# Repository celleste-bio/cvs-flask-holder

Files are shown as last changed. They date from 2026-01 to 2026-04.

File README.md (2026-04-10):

# CVS (Cell Volume after Sedimentation) Apparatus

Parametric OpenSCAD implementations of the **CVS (Cell Volume after Sedimentation) Apparatus**.
 
This project provides a **parametric, 3D-printable model** of the CVS apparatus described by Mustafa et al. (2011). While the measurement method itself is established, this repository offers a flexible design that can be customized to fit any Erlenmeyer flask dimensions, optimizing it for 3D printing and laboratory use.

## Specification Tracking

Manufacturer-backed flask specification tracking lives in [specifications/erlenmeyer-specifications.csv](/root/cvs-flask-holder/specifications/erlenmeyer-specifications.csv) with supporting notes in [specifications/erlenmeyer-spec-sources.md](/root/cvs-flask-holder/specifications/erlenmeyer-spec-sources.md).

Project documentation lives in `documentation/`:

- [project-overview.md](/root/cvs-flask-holder/documentation/project-overview.md)
- [repo-map.md](/root/cvs-flask-holder/documentation/repo-map.md)
- [workflows.md](/root/cvs-flask-holder/documentation/workflows.md)
- [holder-traceability.md](/root/cvs-flask-holder/documentation/holder-traceability.md)
- [flask-id-index.md](/root/cvs-flask-holder/documentation/flask-id-index.md)

The current tracked manufacturer-specific plastic capped line is:

- Tarsons sterile flat-base polycarbonate Erlenmeyer cell culture flasks with vented HDPE closure
  - Source: https://www.tarsons.com/product/sterile-erlenmeyer-cell-culture-flask-flat-base-pc-with-vented-hdpe-closure/
  - Modeled sizes: `125`, `250`, `500`, `1000`, `2000` mL
  - Model folders: `models/tarsons_pc_vented_125ml` through `models/tarsons_pc_vented_2000ml`

The CSV also tracks additional manufacturer resources and metadata such as material family, capped vs. rimmed/open neck, base style, sterility, and closure style for future model work.

Smaller OpenSCAD comparison scenes are available in `scripts/`:

- `compare_classic_open.scad` for the original open-rim flask set
- `compare_tarsons_pc_vented.scad` for all Tarsons plastic capped vented flasks
- `compare_tarsons_pc_vented_small.scad` for Tarsons 125/250/500 mL
- `compare_tarsons_pc_vented_large.scad` for Tarsons 1000/2000 mL

## Scientific Context & Benefits

This apparatus holds Erlenmeyer flasks at a precise **60-degree angle**, transforming a standard flask into a precision measurement tool ("the poor man's real-time sensor").

### Why Use the 60° CVS Apparatus?
Standard flask markings are notoriously inaccurate (5-10% error margin) and designed for liquid volume, not biomass density. This apparatus offers three critical advantages:

#### 1. Amplified Resolution (The "Ruler" Effect)
**The Problem**: In a flat flask, sedimented cells spread in a thin, indistinguishable layer across the wide bottom.
**The 60° Solution**: By tilting the flask, cells are forced into the "corner" (junction of base and wall), concentrating the biomass into a tall column.
**Result**: A <1mm change in biomass (invisible on a flat bottom) becomes a **5–10mm change** along the angled wall, making it easily readable with a standard ruler.

#### 2. Consistency of "Packing"
**The Problem**: Cells (especially cocoa) form aggregates (clumps) that settle loosely and unevenly in vertical flasks due to friction.
**The 60° Solution**: This angle is the "goldilocks" tilt—steep enough for cells to slide to maximum packing density, but stable enough to prevent collapse.
**Result**: Ensures every measurement has uniform packing pressure, creating a **linear correlation to Fresh Weight (FW)**.

#### 3. Non-Destructive Monitoring
**The Problem**: Accurate biomass readings usually require transferring culture to a graduated cylinder or PCV tube, risking contamination and cell loss.
**The 60° Solution**: The apparatus measures the flask *as is*.
**Result**: **Zero contamination risk** and no lost cells. You can track the growth curve of the *exact same flask* throughout the entire cycle.

### Summary Comparison

| Feature | Erlenmeyer Markings | 60° CVS Apparatus |
| :--- | :--- | :--- |
| **Accuracy** | ± 10% (Approximate) | **High** (Correlates to Fresh Weight) |
| **Readability** | Very poor for thin layers | **High** (Vertical height is amplified) |
| **Contamination Risk** | Low | **Zero** (Flask remains sealed) |
| **Suitability for Cocoa** | Poor (Aggregates settle unevenly) | **Excellent** (Optimal packing) |

### Reference Material
> **Reference Paper:**
> Mustafa, N. R., de Winter, W., van Iren, F. & Verpoorte, R. (2011). **Initiation, growth and cryopreservation of plant cell suspension cultures**. *Nature Protocols*, 6(6), 715–742.

*Note: The apparatus provided here is a supplementary tool to facilitate the handling of flasks described in the protocol. It is not the invention claimed in the cited patent (US Patent 5,965,438), which relates to the cryopreservation method itself.*

## Prerequisites

To use and generate these models, you need:
1.  **Lua** (5.1 or later)
2.  **OpenSCAD** (for rendering)
3.  **Git** (to manage dependencies)

## Installation

Clone the repository and initialize the submodules:

```bash
git clone <repository-url>
cd erlenmeyer-holders
git submodule update --init --recursive
```

This will pull the necessary dependencies (`lua-utils` and `lua-openscad`) into the `dependencies/` directory.

## Deployment / Reproduction

To ensure a consistent environment for generating models and documentation, we provide a **Podman** container configuration.

### 1. Build and Run Container
Use the provided helper script to build the image and enter the container shell:

```bash
./deployment/build_and_run.sh
```

### 2. Run Tasks Inside Container
Once inside the container (which mounts the current directory to `/data`), you can run the standard workflows:

**Generate Models:**
```bash
./scripts/model_all.sh
```

**Generate Documentation (PDF):**
```bash
cd publications
make
```

**Slice Models (Generates G-code):**
```bash
./scripts/slice_all.sh
```
*(Note: The container includes a PrusaSlicer AppImage)*

**Package Tarsons Release Files:**
```bash
./scripts/package_tarsons_pc_vented.sh
```
This creates a `distribution/` directory and `.tar.gz` archive containing the final STL/BGCODE files plus a manifest that maps each file to manufacturer, catalog number, capacity, and source specifications.

## Repository Structure

- **`source/`**: Lua scripts replaced `parametric/` that define the parametric 3D geometry.
    - `flask.lua`: Generates the flask shape.
    - `holder.lua`: Generates the holder apparatus.
- **`scripts/`**: Helper shell scripts for batch processing.
- **`models/`**: Contains configuration and generated files for specific flask sizes.
    - **`[size]ml/`** (e.g., `100ml/`, `250ml/`):
        - `measurements.yaml`: Definition of flask dimensions.
        - `*.scad`: Generated OpenSCAD files.
- **`publications/`**: Files for generating the scientific paper documentation (PDF).

- **`dependencies/`**: Local dependencies (submodules).

## Publication

A scientific paper format of this documentation is available in the `publications/` directory. To generate the PDF:

```bash
cd publications
make
```

## Fabrication

We recommend the following equipment and software, which were used to validate the models:

*   **Printer**: [Original Prusa MK4S](https://www.prusa3d.com/product/original-prusa-mk4s-3d-printer/)
*   **Slicer**: [PrusaSlicer](https://www.prusa3d.com/page/prusaslicer_424/)

The provided `slice_all.sh` script is configured for PrusaSlicer CLI.

## Usage

### 1. Configure Dimensions
Edit the `measurements.yaml` file in the desired size folder (e.g., `100ml/measurements.yaml`) to match your specific flask dimensions.

For manufacturer-specific folders, keep two things separate:

- published dimensions copied directly from the source
- modeling assumptions needed by this geometry, such as outer neck diameter when a vendor only publishes inner neck diameter

For traceability, each `measurements.yaml` should also define:

- `flask_id`: full canonical ID for manifests and lookups
- `engraving_id`: short ID engraved on the printed holder
- `manufacturer`, `family_code`, `variant_code`, `capacity_ml`, `revision`: normalized metadata used to explain the ID

See [holder-traceability.md](/root/cvs-flask-holder/documentation/holder-traceability.md) for the full provenance and ID documentation.

The printed holder carries both provenance engravings on the two front base tabs: the Git commit hash on one tab and the short `engraving_id` on the other.

**Required Measurements:**

- **`total_height`**: Absolute height from base to top of rim.
- **`neck_height`**: Length of the neck (including the rim).
- **`base_diameter`**: Diameter of the base at its widest point.
- **`neck_diameter`**: Diameter of the neck (excluding the rim).

*(Note: `body_height` is automatically calculated as `total_height - neck_height`)*

**Example (250ml Flask):**

```yaml
total_height: 13.3  # cm
neck_height: 1.0    # cm (with rim)
base_diameter: 8.0  # cm
neck_diameter: 3.7  # cm (without rim)
```

### 2. Generate Models
Use Lua to run the parametric scripts.

**Generate a Flask Model:**
```bash
lua source/flask.lua models/100ml/measurements.yaml models/100ml/flask.scad
```

**Generate a Holder Model:**
```bash
lua source/holder.lua models/100ml/measurements.yaml models/100ml/holder.scad
```

**Generate a Holder with Flask Visualization:**
```bash
# The 'true' argument adds a visual ghost of the flask to check fit
lua source/holder.lua models/100ml/measurements.yaml models/100ml/holder_with_flask.scad true
```

### 3. Batch Processing
Use the provided shell scripts (ensure they are executable: `chmod +x *.sh`):

- **Generate All SCAD Files**:
  ```bash
  ./scripts/model_all.sh
  ```
- **Render All to STL**:
  ```bash
  ./scripts/render_all.sh
  ```
- **Slice All** (Requires PrusaSlicer CLI configuration):
  ```bash
  ./scripts/slice_all.sh
  ```
- **Run the Full Pipeline**:
  ```bash
  ./scripts/build_all.sh
  ```
  This generates SCAD files, renders STL files, slices BGCODE, and exports PNG previews for every `scripts/compare*.scad` scene into `artifacts/compare/`.
- **Package Manufacturer-Tracked Tarsons Outputs**:
  ```bash
  ./scripts/package_tarsons_pc_vented.sh
  ```

## License

**MIT License**

Copyright (c) 2026 Celleste Bio

Permission is hereby granted, free of charge, to any person obtaining a copy of this software and associated documentation files (the "Software"), to deal in the Software without restriction, including without limitation the rights to use, copy, modify, merge, publish, distribute, sublicense, and/or sell copies of the Software, and to permit persons to whom the Software is furnished to do so, subject to the following conditions:

The above copyright notice and this permission notice shall be included in all copies or substantial portions of the Software.

THE SOFTWARE IS PROVIDED "AS IS", WITHOUT WARRANTY OF ANY KIND, EXPRESS OR IMPLIED, INCLUDING BUT NOT LIMITED TO THE WARRANTIES OF MERCHANTABILITY, FITNESS FOR A PARTICULAR PURPOSE AND NONINFRINGEMENT. IN NO EVENT SHALL THE AUTHORS OR COPYRIGHT HOLDERS BE LIABLE FOR ANY CLAIM, DAMAGES OR OTHER LIABILITY, WHETHER IN AN ACTION OF CONTRACT, TORT OR OTHERWISE, ARISING FROM, OUT OF OR IN CONNECTION WITH THE SOFTWARE OR THE USE OR OTHER DEALINGS IN THE SOFTWARE.

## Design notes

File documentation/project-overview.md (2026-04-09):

# Project Overview

This repository contains a parametric CAD workflow for generating 3D-printable CVS (Cell Volume after Sedimentation) flask holders.

## Purpose

The holder fixes an Erlenmeyer flask at a repeatable tilt so sedimented biomass forms a readable column along the flask wall. The geometry is driven from flask dimensions stored in per-model YAML files.

## Core Design Idea

A flask model is defined by measurements in `models/<model>/measurements.yaml`.

From that YAML:

- `source/flask.lua` generates a flask visualization model
- `source/holder.lua` generates the printable holder geometry
- scripts in `scripts/` batch-generate SCAD, STL, BGCODE, and release packages

## Main Data Flow

1. Define or update a flask model in `models/.../measurements.yaml`.
2. Generate SCAD files from the Lua geometry sources.
3. Render STL files from SCAD.
4. Slice toolpaths for printing.
5. Package release artifacts when needed.

## Documentation Layout

Project-level documentation now lives in `documentation/`:

- `project-overview.md`: what the repo does and how it is organized
- `holder-traceability.md`: provenance and engraving model
- `flask-id-index.md`: registry of current short IDs and full IDs
- `repo-map.md`: structure guide for the repository
- `workflows.md`: practical generation and release workflow notes

## Specifications Layout

The `specifications/` directory is reserved for flask specification sources and source-backed records such as:

- manufacturer-backed specification tables
- source capture notes
- future source-specific supporting material

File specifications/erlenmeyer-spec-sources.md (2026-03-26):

# Erlenmeyer Specification Tracking

This repository now tracks manufacturer-backed Erlenmeyer flask specifications in [erlenmeyer-specifications.csv](/root/cvs-flask-holder/specifications/erlenmeyer-specifications.csv).

## Primary Modeling Source

- Tarsons: Sterile Erlenmeyer Cell Culture Flask, Flat base, PC with vented HDPE Closure
  - URL: https://www.tarsons.com/product/sterile-erlenmeyer-cell-culture-flask-flat-base-pc-with-vented-hdpe-closure/
  - Sizes published on the product page: 125, 250, 500, 1000, 2000 mL
  - Published dimensions captured in the dataset: bottom outer diameter, inner neck diameter, height without closure, height with closure, closure finish
  - Metadata captured: plastic, capped, vented, threaded, sterile, autoclavable, flat-base

## Additional Manufacturer Resources

- DWK Life Sciences, PYREX narrow-neck glass flasks
  - URL: https://www.dwk.com/pyrex-flasks-conical-narrow-neck-125-ml-113008d
  - Useful for glass, rimmed/open, narrow-neck reference dimensions
  - Product page exposes body OD, neck ID, and height

- DWK Life Sciences, DURAN narrow-neck glass flasks
  - URL: https://www.dwk.com/duran-erlenmeyer-flask-narrow-neck-1000-ml-212165409
  - Useful for ISO-style borosilicate glass reference families and larger capacities
  - Product page confirms glass material and narrow-neck family; dimensions should be pulled from the live spec table when modeling a specific size

- Thermo Fisher Scientific, Nalgene single-use PETG Erlenmeyer flasks
  - URL: https://www.thermofisher.com/order/catalog/product/ar/en/4115-0500
  - Useful for plastic, threaded, capped plain-bottom families
  - Family page covers vented and solid caps across 125, 250, 500, 1000, 2000, and 2800 mL

- Corning polycarbonate Erlenmeyer flasks
  - URL: https://ecatalog.corning.com/life-sciences/b2c/US/en/Bioprocess-and-Scale-up/Erlenmeyer-Flasks/Erlenmeyer-Flasks-Plastic/Corning%C2%AE-Polycarbonate-Erlenmeyer-Flask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
  - Useful for sterile disposable plastic flask families with vented and baffled variants
  - Family pages are good references for cap style, neck style, bottom style, sterility, and size availability

## Modeling Assumptions For Tarsons

Tarsons publishes `Inner Neck Diameter` and thread finish, but not the outer neck diameter required by this holder model. For the new Tarsons models:

- `total_height` uses the published `Height w/out closure`
- `base_diameter` uses the published `Bottom Outer Diameter`
- `neck_diameter` uses the published thread finish as the best available outer-neck proxy
- `neck_height` is an explicit modeling estimate and is marked as such in each `measurements.yaml`

If direct caliper measurements become available, update the Tarsons folders first and then regenerate the SCAD/STL outputs.

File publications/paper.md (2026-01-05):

---
title: "Parametric Design and Fabrication of CVS Apparatus: An Improved Method for Biomass Measurement"
author:
- Celleste Bio
date: 2026-01-05
abstract: |
  We present a parametric OpenSCAD implementation of the Cell Volume after Sedimentation (CVS) apparatus originally described by @mustafa2011initiation. By enabling the accessible fabrication of this tool via 3D printing, we provide an improved method for biomass measurement that is significantly faster, easier, and less traumatic to cell samples than traditional techniques. Our primary contribution is a fully customizable, parametric CAD design that allows researchers to adapt the apparatus to any Erlenmeyer flask dimension, facilitating widespread adoption of this non-destructive and sterile workflow.
bibliography: references.bib
csl: https://www.zotero.org/styles/nature
geometry:
  - margin=2cm
---

# Introduction

Accurate measurement of biomass in plant cell suspension cultures is frequently bottlenecked by methods that are either destructive, time-consuming, or prone to contamination. The CVS method offers a superior alternative—a "poor man's real-time sensor"—that transforms a standard flask into a precision measurement tool.

We provide a parametric model to democratize access to this method. Our goal is to replace ad-hoc laboratory setups with a robust, reproducible, and 3D-printable design. This approach minimizes the barrier to entry, allowing any laboratory to implement a rapid, non-destructive monitoring workflow tailored to their specific glassware inventory.

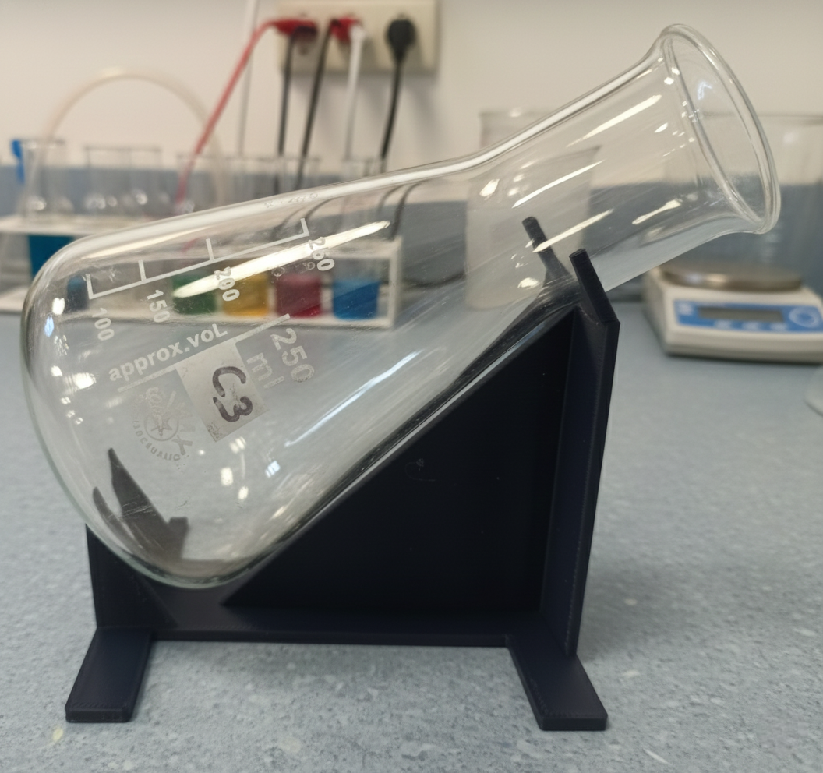
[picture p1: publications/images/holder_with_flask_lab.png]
CVS Apparatus in a laboratory setting.


# Parametric Model Configuration

To ensure the apparatus fits the flask securely and provides accurate sedimentation angles, the model requires specific dimensions of the user's flask. These are defined in a YAML configuration file.

The required measurements are:

*   **`total_height`**: The absolute vertical height of the flask from base to the top of the rim.
*   **`neck_height`**: The length of the neck, including the rim.
*   **`base_diameter`**: The diameter of the widest part of the base.
*   **`neck_diameter`**: The diameter of the neck (measured below the rim).

The **`body_height`** (the conical section) is automatically derived as `total_height - neck_height`.

## Example Configuration (250ml Flask)

For a standard 250ml Erlenmeyer flask, the configuration would be:

```yaml
# 250ml Flask Dimensions
total_height: 13.3   # cm
neck_height: 1.0     # cm (includes rim)
base_diameter: 8.0   # cm
neck_diameter: 3.7   # cm (excludes rim)
```

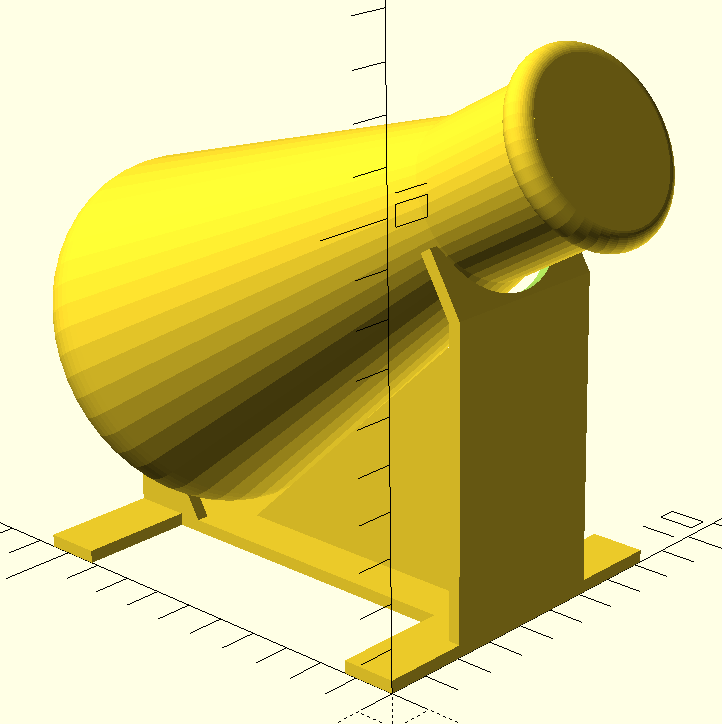
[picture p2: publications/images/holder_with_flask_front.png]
Front view: With Flask (Left) and Without Flask (Right).
 \ \ 
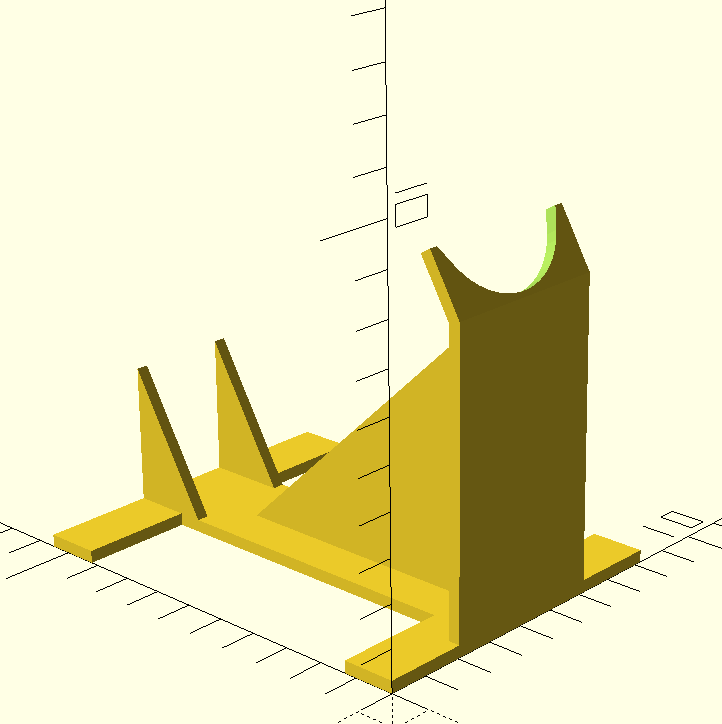
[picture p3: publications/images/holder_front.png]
Front view: Without Flask.


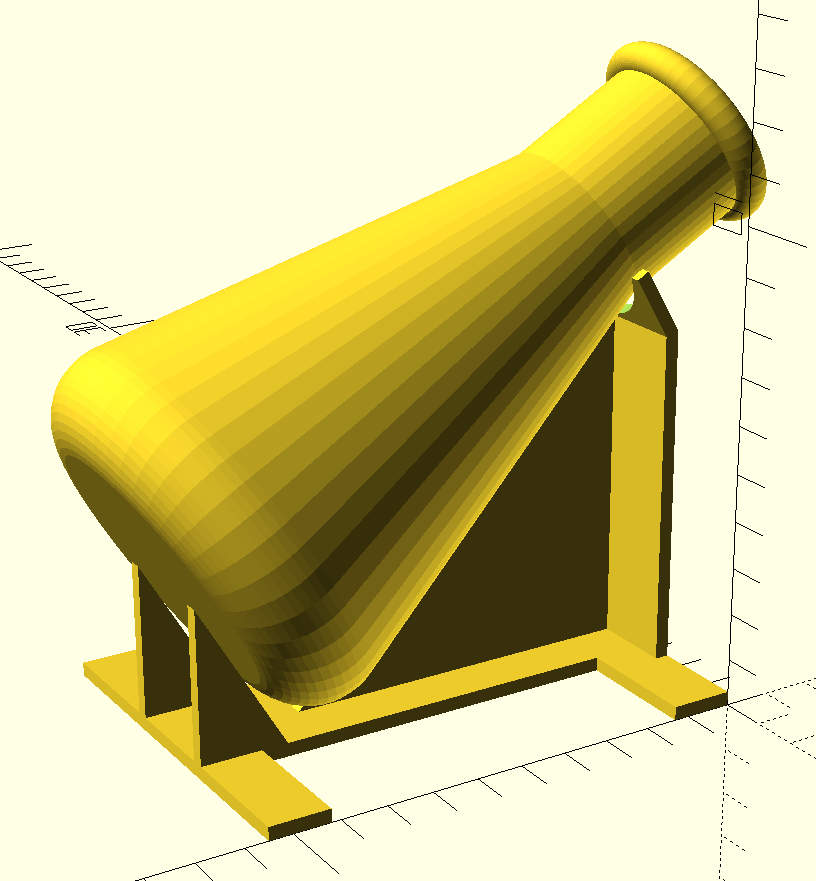
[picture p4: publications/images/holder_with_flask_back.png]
Back view: With Flask (Left) and Without Flask (Right).
 \ \ 
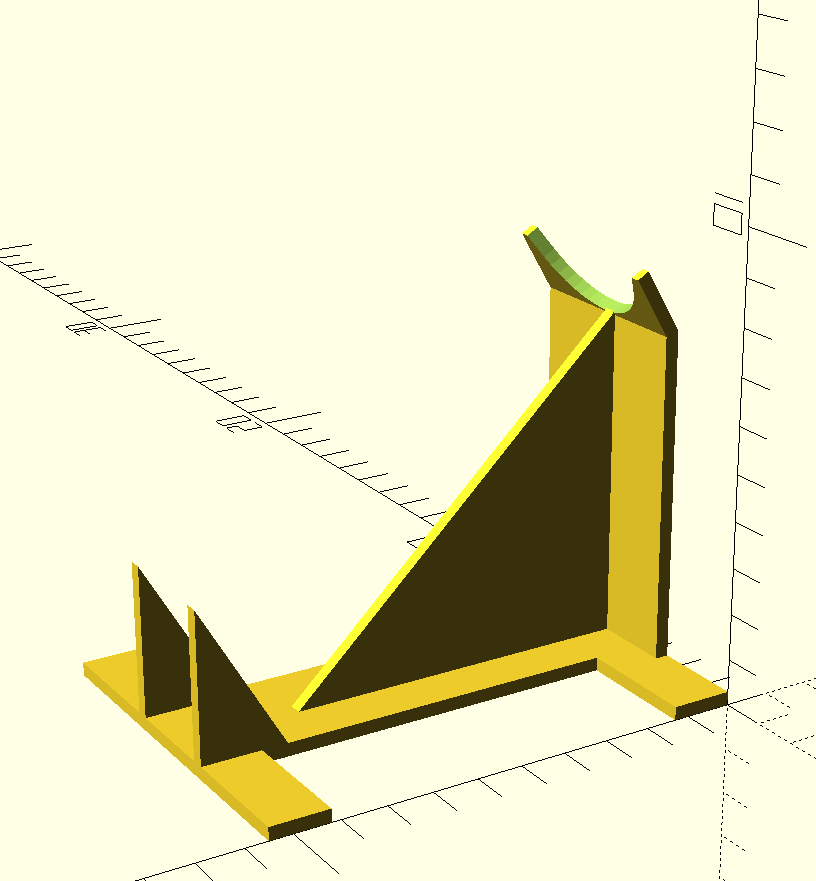
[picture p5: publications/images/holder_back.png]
Back view: Without Flask.


# Principles and Benefits

The CVS apparatus holds flasks at a fixed 60-degree angle, enabling a workflow that simplifies biomass monitoring while preserving sample integrity.

## Enhanced Readability
In a flat flask, sedimented cells spread in a thin, indistinguishable layer across the wide bottom. By tilting the flask, cells are forced into the junction of the base and the wall, concentrating the biomass into a tall column. This geometric amplification translates a negligible <1 mm height difference into a clear 5–10 mm change along the angled wall, making it faster and easier to read with a standard ruler.

## Standardized Measurement
Cells, particularly those of *Theobroma cacao* (cocoa), often form aggregates that settle unevenly in vertical flasks. The 60-degree angle provides an optimal tilt—steep enough for cells to slide to maximum packing density under gravity, yet stable enough to prevent collapse. This consistency eliminates the variability of manual handling and ensures distinct, reproducible measurements.

## Non-Traumatic and Sterile Workflow
Unlike traditional sampling which requires opening the flask and breaking the sterile barrier, this method measures the flask *as is*. This results in a completely **sterile workflow** with **zero contamination risk**. Furthermore, because the sample is not removed or mechanically disturbed, the process is non-traumatic for the cells, allowing for continuous monitoring of the exact same culture throughout its growth cycle.

# Method Comparison

We compare the CVS apparatus with the traditional **Packed Cell Volume (PCV)** method, which involves centrifuging a sub-sample of the culture (typically 10-15 mL) in a 50 mL Falcon tube. While PCV provides a direct volumetric measurement, it introduces significant drawbacks regarding sterility and sample integrity.

| Feature | Packed Cell Volume (PCV) | 60° CVS Apparatus |
| :--- | :--- | :--- |
| **Contamination Risk** | **High** (Breaks sterile barrier) | **Zero** (Flask remains sealed) |
| **Sample Representativeness** | **Variable** (Sub-sample dependent) | **Complete** (Measures whole culture) |
| **Material Loss** | **Yes** (Destructive sub-sampling) | **None** (Non-destructive) |
| **Time Cost** | **High** (Pipetting, Centrifugation) | **Low** (Instant visual read) |
| **Equipment** | **Significant** (Centrifuge, tubes, tips) | **Minimal** (3D Printed Holder, Ruler) |
| **Measurement Accuracy** | **High** (For the sub-sample) | **High** (Amplified height, correlates to fresh weight) |

# Fabrication

The models were optimized for fabrication using **Fused Deposition Modeling (FDM)** 3D printing. We utilized the **[Original Prusa MK4S](https://www.prusa3d.com/product/original-prusa-mk4s-3d-printer/)** 3D printer for its reliability and precision.

Preprocessing and slicing were performed using **[PrusaSlicer](https://www.prusa3d.com/page/prusaslicer_424/)**, which ensures optimal toolpath generation for structural integrity and print quality. The batch processing scripts provided in the repository utilize the PrusaSlicer CLI interface to automate the generation of G-code for multiple flask sizes.

# References
The apparatus described here serves as a supplementary tool to facilitate the handling of flasks described in the protocol by @mustafa2011initiation. Note that this tool is not the invention claimed in the cited patent (US Patent 5,965,438), which relates to the cryopreservation method itself.

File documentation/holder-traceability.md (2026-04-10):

# Holder Traceability

This document explains how holder provenance is encoded, how flask IDs are assigned, and how to trace a printed holder back to the exact modeled flask definition.

## Provenance Layers

Each holder is intended to carry two engraved identifiers:

- Git commit hash: identifies the code revision that generated the holder geometry
- `engraving_id`: identifies the intended flask model in a compact print-friendly format

Both markings are engraved into the two front base tabs so they remain visible from the same viewing side of the printed holder.

The engraved flask code is short on purpose. The full source-of-truth identity and supporting metadata live in the corresponding `measurements.yaml` file.

## Metadata Layers

Each flask model should define these metadata fields in `measurements.yaml`:

- `flask_id`: full canonical identifier used for indexing and documentation
- `engraving_id`: compact identifier engraved on the holder
- `manufacturer`: source manufacturer or `Generic`
- `family_code`: normalized family grouping such as `erlenmeyer` or `cellculture`
- `variant_code`: normalized variant such as `open` or `vented`
- `capacity_ml`: nominal flask capacity in mL
- `revision`: revision number for the modeled measurement definition

Manufacturer-specific models can also include:

- `catalog_no`
- `product_line`
- `source_url`
- published source dimensions
- notes about modeling assumptions

## Why Two IDs Exist

A single full identifier is useful for indexing but often too long for clean engraving. A single short identifier is easy to engrave but too compressed to serve as the only documentation key.

Using both solves that tradeoff:

- `engraving_id` keeps the physical holder readable
- `flask_id` keeps the repository searchable and explainable

## Engraving ID Format

```text
{maker}{capacity}{variant}{revision}
```

Examples:

- `G250O1` = Generic, 250 mL, open, revision 1
- `T250V1` = Tarsons, 250 mL, vented, revision 1
- `T1KV1` = Tarsons, 1000 mL, vented, revision 1

See [flask-id-index.md](/root/cvs-flask-holder/documentation/flask-id-index.md) for the code tables and current registry.

## Canonical Full ID Format

```text
{manufacturer}-{family_code}-{capacity_ml}-{variant_code}-v{revision}
```

Examples:

- `generic-erlenmeyer-0250-open-v1`
- `tarsons-cellculture-0250-vented-v1`

The full ID is the durable repository key and should be used in manifests, release notes, and any future packaging metadata.

## Example

```yaml
flask_id: tarsons-cellculture-0250-vented-v1
engraving_id: T250V1
manufacturer: Tarsons
family_code: cellculture
variant_code: vented
capacity_ml: 250
revision: 1
catalog_no: 444220
```

## How To Trace A Printed Holder

1. Read the Git commit engraving from the holder.
2. Read the short `engraving_id` from the adjacent front tab.
3. Look up the short ID in [flask-id-index.md](/root/cvs-flask-holder/documentation/flask-id-index.md).
4. Open the corresponding `models/.../measurements.yaml` file.
5. Use `flask_id`, source fields, and notes to recover the exact modeled flask definition.

## Authoring Rules

- Keep `engraving_id` short enough to print clearly.
- Keep `flask_id` descriptive and stable.
- Do not reuse an existing ID for different dimensions.
- Increment `revision` when modeled dimensions or dimensional interpretation change materially.
- Keep manufacturer source values and modeling assumptions separate when both are needed.

## Maintenance Workflow

When adding or revising a flask model:

1. Add or update the normalized metadata in `measurements.yaml`.
2. Assign a new `engraving_id` and `flask_id` if needed.
3. Update [flask-id-index.md](/root/cvs-flask-holder/documentation/flask-id-index.md).
4. Regenerate SCAD files so the physical engraving matches the metadata.
5. Regenerate downstream STL or toolpath artifacts as needed.

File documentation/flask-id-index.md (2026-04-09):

# Flask ID Index

This repository uses two ID layers for holder provenance:

- `engraving_id`: short code engraved on the holder
- `flask_id`: full canonical ID stored in `measurements.yaml`

The short code is optimized for readability and reliable printing. The full ID is optimized for indexing, search, and documentation.

## Engraving ID Format

```text
{maker}{capacity}{variant}{revision}
```

Examples:

- `G250O1` = Generic, 250 mL, open, revision 1
- `T250V1` = Tarsons, 250 mL, vented, revision 1
- `T1KV1` = Tarsons, 1000 mL, vented, revision 1

## Code Tables

### Maker Codes

- `G` = Generic or legacy reference flask
- `T` = Tarsons
- `D` = DWK
- `C` = Corning
- `H` = Thermo Fisher

### Capacity Codes

- `100`, `125`, `250`, `500` = capacity in mL
- `1K` = 1000 mL
- `2K` = 2000 mL
- `2P8K` = 2800 mL if needed in the future

### Variant Codes

- `O` = open rim
- `V` = vented cap
- `S` = solid or screw cap
- `B` = baffled

### Revision

The trailing number is the revision of the modeled measurement set.

- `1` = first tracked measurement definition
- `2` = updated measurement definition, same family and capacity

Increment the revision when the modeled dimensions or their interpretation change in a way that should remain traceable.

## Canonical Full ID Format

```text
{manufacturer}-{family_code}-{capacity_ml}-{variant_code}-v{revision}
```

Examples:

- `generic-erlenmeyer-0250-open-v1`
- `tarsons-cellculture-0250-vented-v1`

The full ID is the durable repo key. Use it in manifests, documentation, and any future packaging metadata.

## Current Registry

| Model Folder | Engraving ID | Full ID |
| :--- | :--- | :--- |
| `models/100ml` | `G100O1` | `generic-erlenmeyer-0100-open-v1` |
| `models/250ml` | `G250O1` | `generic-erlenmeyer-0250-open-v1` |
| `models/500ml` | `G500O1` | `generic-erlenmeyer-0500-open-v1` |
| `models/1000ml` | `G1KO1` | `generic-erlenmeyer-1000-open-v1` |
| `models/tarsons_pc_vented_125ml` | `T125V1` | `tarsons-cellculture-0125-vented-v1` |
| `models/tarsons_pc_vented_250ml` | `T250V1` | `tarsons-cellculture-0250-vented-v1` |
| `models/tarsons_pc_vented_500ml` | `T500V1` | `tarsons-cellculture-0500-vented-v1` |
| `models/tarsons_pc_vented_1000ml` | `T1KV1` | `tarsons-cellculture-1000-vented-v1` |
| `models/tarsons_pc_vented_2000ml` | `T2KV1` | `tarsons-cellculture-2000-vented-v1` |

## How To Trace A Printed Holder

1. Read the Git commit engraving and locate the code revision.
2. Read the short `engraving_id` and look it up in this index.
3. Open the matching `models/.../measurements.yaml` file.
4. Use `flask_id`, source fields, and notes to recover the exact modeled flask definition.

## Authoring Rules

- Keep `engraving_id` short enough to print clearly.
- Keep `flask_id` descriptive and stable.
- Do not recycle an existing ID for different dimensions.
- Bump the revision when measurements or modeling assumptions change materially.

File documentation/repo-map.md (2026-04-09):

# Repository Map

This document gives a practical map of the repository so it is easier to locate source code, generated artifacts, specifications, and publishing materials.

## Top-Level Layout

- `README.md`: short project entry point
- `documentation/`: project documentation and navigation aids
- `source/`: parametric geometry source code in Lua
- `models/`: per-flask model definitions and generated outputs
- `scripts/`: batch generation, rendering, slicing, comparison, and packaging helpers
- `specifications/`: source-backed flask specification records
- `distribution/`: packaged release outputs
- `artifacts/`: generated comparison images and similar derived outputs
- `deployment/`: containerized build environment helpers
- `publications/`: paper manuscript, references, and rendered publication assets
- `dimensions/`: exploratory dimensional analysis inputs and notes
- `dependencies/`: vendored or submodule dependencies used by the geometry code

## Source Code

### `source/`

- `flask.lua`: builds the flask reference geometry used for visualization and fit checks
- `holder.lua`: builds the printable holder geometry and engravings

## Model Definitions And Outputs

### `models/`

Each subdirectory represents one flask model.

Typical contents:

- `measurements.yaml`: source-of-truth dimensions and metadata
- `flask.scad`: generated flask geometry
- `holder.scad`: generated holder geometry
- `holder_with_flask.scad`: generated holder plus flask visualization
- `holder.stl`: rendered printable mesh
- `holder.bgcode`: sliced print output

Current families include:

- generic open Erlenmeyer reference sizes
- Tarsons vented cell culture flasks

## Scripts

### `scripts/`

Operational entry points:

- `model_all.sh`: generate SCAD for all models
- `render_all.sh`: render STL files
- `slice_all.sh`: slice print jobs
- `build_all.sh`: run the full main pipeline
- `package_tarsons_pc_vented.sh`: create Tarsons release packages

Comparison scenes:

- `compare_all.scad`
- `compare_classic_open.scad`
- `compare_tarsons_pc_vented.scad`
- `compare_tarsons_pc_vented_small.scad`
- `compare_tarsons_pc_vented_large.scad`

## Documentation

### `documentation/`

- `project-overview.md`: project-level orientation
- `workflows.md`: build and maintenance workflows
- `holder-traceability.md`: holder provenance model
- `flask-id-index.md`: short-ID registry and decoding table
- `repo-map.md`: this file

## Specifications

### `specifications/`

This directory is reserved for specification material and source-backed records:

- `erlenmeyer-specifications.csv`: tracked manufacturer or source rows
- `erlenmeyer-spec-sources.md`: notes about where each specification came from

## Publication Material

### `publications/`

- `paper.md`: manuscript source
- `references.bib`: bibliography
- `paper.pdf`: built paper output
- `images/`: paper figures

## Build Environment

### `deployment/`

- `Containerfile`: reproducible container definition
- `build_and_run.sh`: helper to enter the build environment

## Derived Output Areas

### `artifacts/`

Stores generated visual comparison outputs.

### `distribution/`

Stores packaged release bundles prepared for sharing or fabrication handoff.

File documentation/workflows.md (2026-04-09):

# Workflows

This document summarizes the main operational workflows for the repository.

## Model Authoring Workflow

1. Pick or create a model folder under `models/`.
2. Edit `measurements.yaml` with dimensions and metadata.
3. Assign `flask_id` and `engraving_id`.
4. Keep published source values and modeling assumptions separate when manufacturer data is incomplete.

## Geometry Generation Workflow

Use the batch generator:

```bash
./scripts/model_all.sh
```

This produces:

- `flask.scad`
- `holder.scad`
- `holder_with_flask.scad`

## Rendering Workflow

Render STL files from generated SCAD:

```bash
./scripts/render_all.sh
```

## Slicing Workflow

Generate printer toolpaths:

```bash
./scripts/slice_all.sh
```

## Full Build Workflow

Run the full generation pipeline:

```bash
./scripts/build_all.sh
```

This is the most convenient path when model definitions or generator logic changes.

## Packaging Workflow

For the tracked Tarsons vented family:

```bash
./scripts/package_tarsons_pc_vented.sh
```

This prepares a release bundle under `distribution/`.

## When To Regenerate Artifacts

Regenerate SCAD files when:

- `source/flask.lua` changes
- `source/holder.lua` changes
- any `measurements.yaml` changes
- engraving or provenance logic changes

Regenerate STL and slicing outputs when:

- geometry changes
- print settings change
- release bundles need refreshing

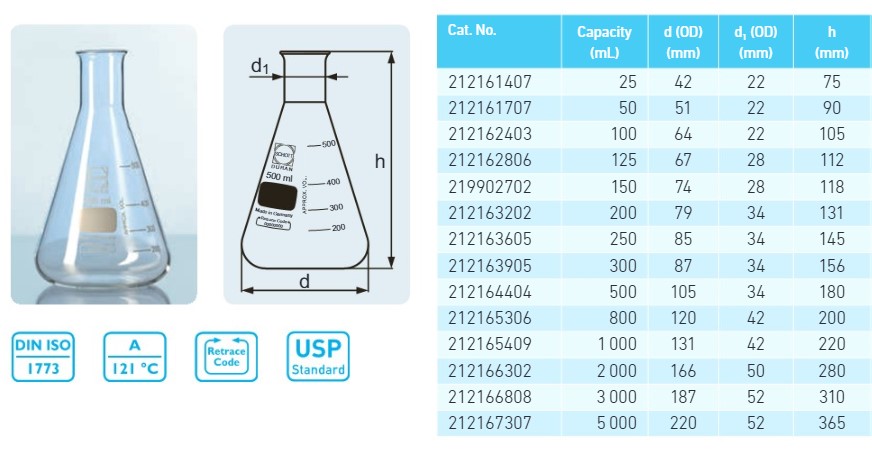
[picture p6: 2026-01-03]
dimensions/erlenmeyer-dimensions.jpg

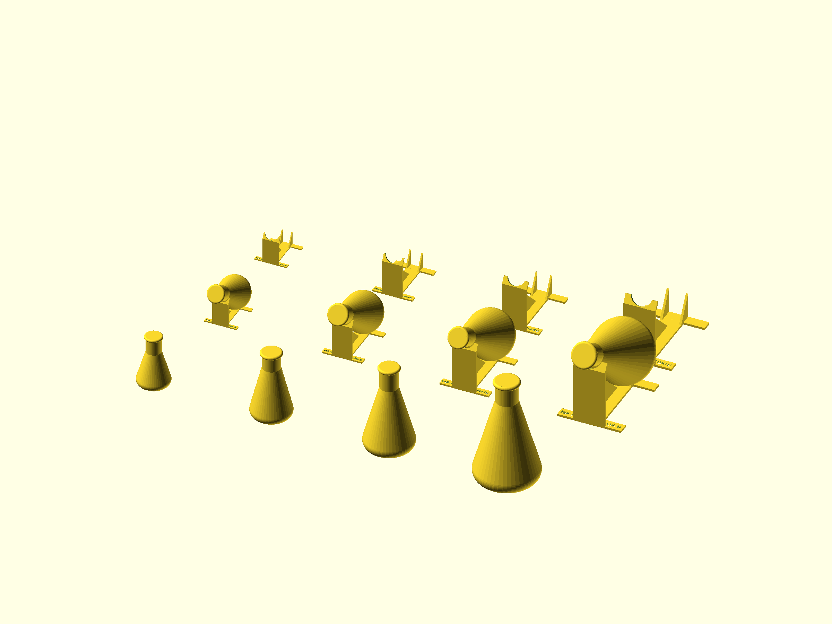
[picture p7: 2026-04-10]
artifacts/compare/compare_classic_open.png

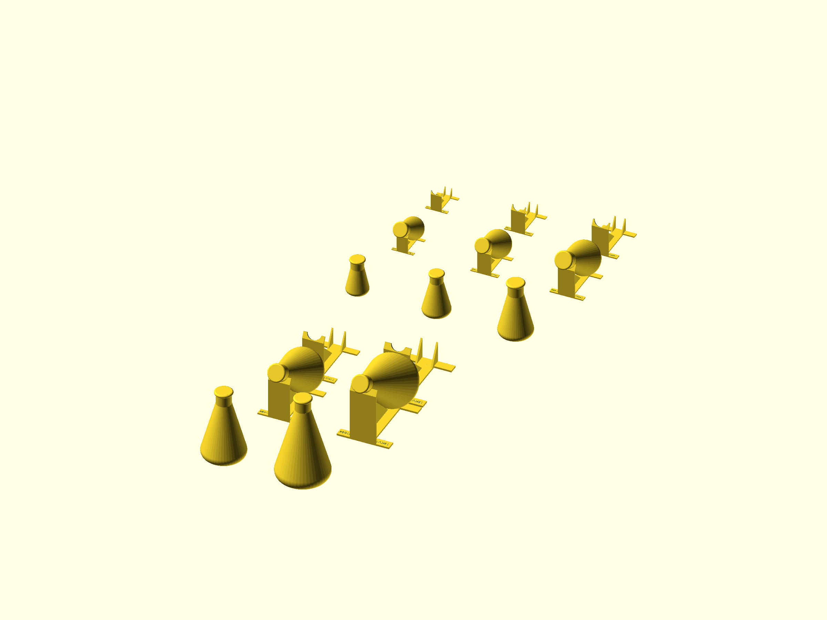
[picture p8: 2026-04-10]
artifacts/compare/compare_tarsons_pc_vented.png

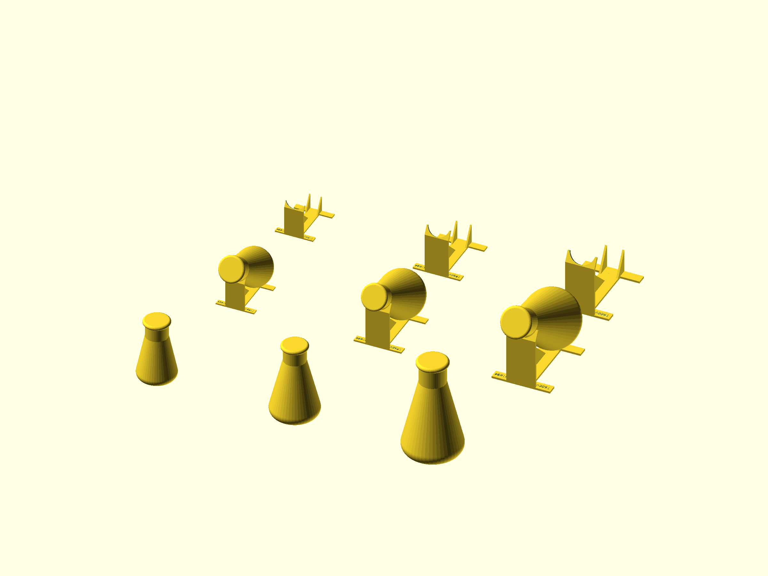
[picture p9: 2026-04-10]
artifacts/compare/compare_tarsons_pc_vented_small.png

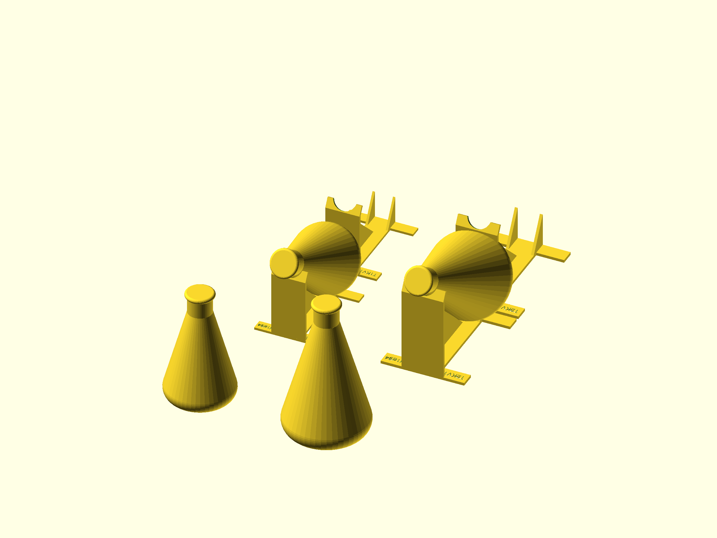
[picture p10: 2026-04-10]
artifacts/compare/compare_tarsons_pc_vented_large.png

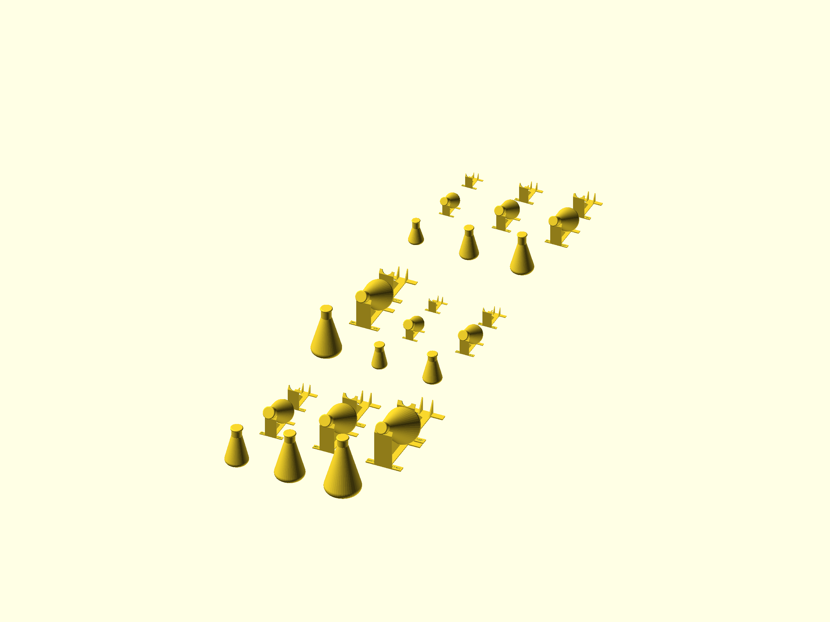
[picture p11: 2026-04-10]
artifacts/compare/compare_all.png

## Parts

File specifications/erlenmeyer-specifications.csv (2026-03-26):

model_id | manufacturer | product_line | capacity_ml | material | closure_material | closure_style | neck_style | base_type | rimmed_or_capped | sterile | autoclavable | baffles | modeled | total_height_mm | base_diameter_mm | neck_diameter_mm | neck_height_mm | source_total_height_without_closure_mm | source_total_height_with_closure_mm | source_base_diameter_mm | source_inner_neck_diameter_mm | source_closure_size | source_catalog_no | source_url | notes
tarsons_pc_vented_125ml | Tarsons | Sterile Erlenmeyer Cell Culture Flask Flat Base PC with vented HDPE Closure | 125 | polycarbonate | HDPE | vented screw cap | threaded | flat | capped | true | true | false | true | 110.0 | 66.5 | 38.0 | 30.0 | 110.0 | 113.9 | 66.5 | 28.5 | 38-430 | 444210 | https://www.tarsons.com/product/sterile-erlenmeyer-cell-culture-flask-flat-base-pc-with-vented-hdpe-closure/ | Model uses published bottom OD and height without closure. Neck diameter is modeled from thread finish because Tarsons publishes inner neck diameter, not outer neck diameter.
tarsons_pc_vented_250ml | Tarsons | Sterile Erlenmeyer Cell Culture Flask Flat Base PC with vented HDPE Closure | 250 | polycarbonate | HDPE | vented screw cap | threaded | flat | capped | true | true | false | true | 134.0 | 82.7 | 38.0 | 30.0 | 134.0 | 139.0 | 82.7 | 28.5 | 38-430 | 444220 | https://www.tarsons.com/product/sterile-erlenmeyer-cell-culture-flask-flat-base-pc-with-vented-hdpe-closure/ | Model uses published bottom OD and height without closure. Neck diameter is modeled from thread finish because Tarsons publishes inner neck diameter, not outer neck diameter.
tarsons_pc_vented_500ml | Tarsons | Sterile Erlenmeyer Cell Culture Flask Flat Base PC with vented HDPE Closure | 500 | polycarbonate | HDPE | vented screw cap | threaded | flat | capped | true | true | false | true | 174.0 | 101.5 | 45.0 | 40.0 | 174.0 | 178.3 | 101.5 | 35.1 | 45-430 | 444230 | https://www.tarsons.com/product/sterile-erlenmeyer-cell-culture-flask-flat-base-pc-with-vented-hdpe-closure/ | Model uses published bottom OD and height without closure. Neck diameter is modeled from thread finish because Tarsons publishes inner neck diameter, not outer neck diameter.
tarsons_pc_vented_1000ml | Tarsons | Sterile Erlenmeyer Cell Culture Flask Flat Base PC with vented HDPE Closure | 1000 | polycarbonate | HDPE | vented screw cap | threaded | flat | capped | true | true | false | true | 218.0 | 129.7 | 45.0 | 40.0 | 218.0 | 222.2 | 129.7 | 35.1 | 45-430 | 444240 | https://www.tarsons.com/product/sterile-erlenmeyer-cell-culture-flask-flat-base-pc-with-vented-hdpe-closure/ | Model uses published bottom OD and height without closure. Neck diameter is modeled from thread finish because Tarsons publishes inner neck diameter, not outer neck diameter.
tarsons_pc_vented_2000ml | Tarsons | Sterile Erlenmeyer Cell Culture Flask Flat Base PC with vented HDPE Closure | 2000 | polycarbonate | HDPE | vented screw cap | threaded | flat | capped | true | true | false | true | 267.5 | 158.6 | 45.0 | 40.0 | 267.5 | 270.5 | 158.6 | 35.4 | 45-430 | 444250 | https://www.tarsons.com/product/sterile-erlenmeyer-cell-culture-flask-flat-base-pc-with-vented-hdpe-closure/ | Model uses published bottom OD and height without closure. Neck diameter is modeled from thread finish because Tarsons publishes inner neck diameter, not outer neck diameter.
dwk_pyrex_125ml | DWK Life Sciences | PYREX Flasks conical narrow neck | 125 | borosilicate glass |  | open narrow neck | narrow neck | flat | rimmed | false | true | false | false | 117.0 | 69.0 | 28.0 |  | 117.0 |  | 69.0 | 28.0 |  | 1130/08D | https://www.dwk.com/pyrex-flasks-conical-narrow-neck-125-ml-113008d | Official glass reference with published capacity, neck ID, body OD, and height.
dwk_duran_1000ml | DWK Life Sciences | DURAN Erlenmeyer Flask narrow neck | 1000 | borosilicate glass |  | open narrow neck | narrow neck | flat | rimmed | false | true | false | false |  |  |  |  |  |  |  | 212165409 | https://www.dwk.com/duran-erlenmeyer-flask-narrow-neck-1000-ml-212165409 | Official glass manufacturer reference. Product page confirms borosilicate glass 3.3 narrow-neck family; dimension extraction should be done from the live spec table before modeling.
thermo_nalgene_petg_plain_family | Thermo Fisher Scientific | Nalgene Single-Use PETG Erlenmeyer Flasks with Plain Bottom Sterile |  | PETG | polypropylene | vented or solid screw cap | threaded | plain | capped | true | false | false | false |  |  |  |  |  |  |  |  | https://www.thermofisher.com/order/catalog/product/ar/en/4115-0500 | Family reference covering 125, 250, 500, 1000, 2000, and 2800 mL plain-bottom PETG flasks with vented and non-vented closure variants.
corning_pc_family | Corning | Corning Polycarbonate Erlenmeyer Flasks |  | polycarbonate | polypropylene | vented or flat cap | threaded | flat or baffled | capped | true | false | true | false |  |  |  |  |  |  |  |  | https://ecatalog.corning.com/life-sciences/b2c/US/en/Bioprocess-and-Scale-up/Erlenmeyer-Flasks/Erlenmeyer-Flasks-Plastic/Corning%C2%AE-Polycarbonate-Erlenmeye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 | Official plastic manufacturer family reference for disposable sterile threaded flasks; family includes vented-cap and baffled variants at multiple sizes.

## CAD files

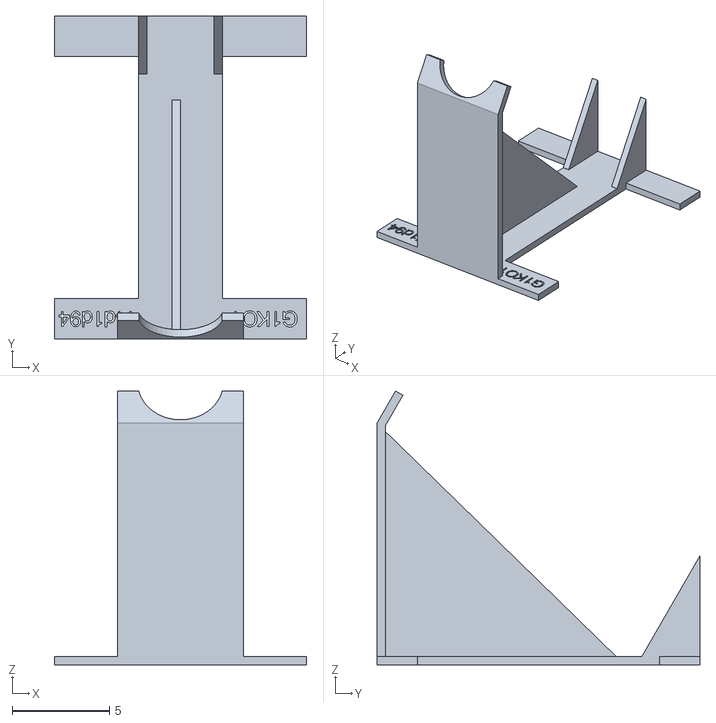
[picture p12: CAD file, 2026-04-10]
models/1000ml/holder.stl
13.0 x 16.6 x 14.1

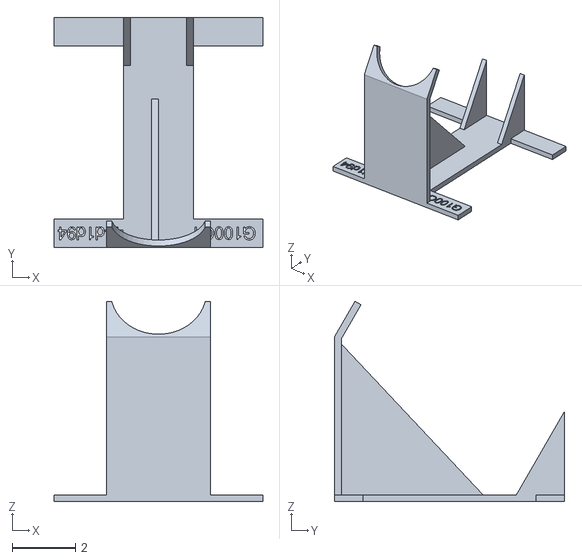
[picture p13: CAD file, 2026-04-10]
models/100ml/holder.stl
6.60 x 7.27 x 6.33

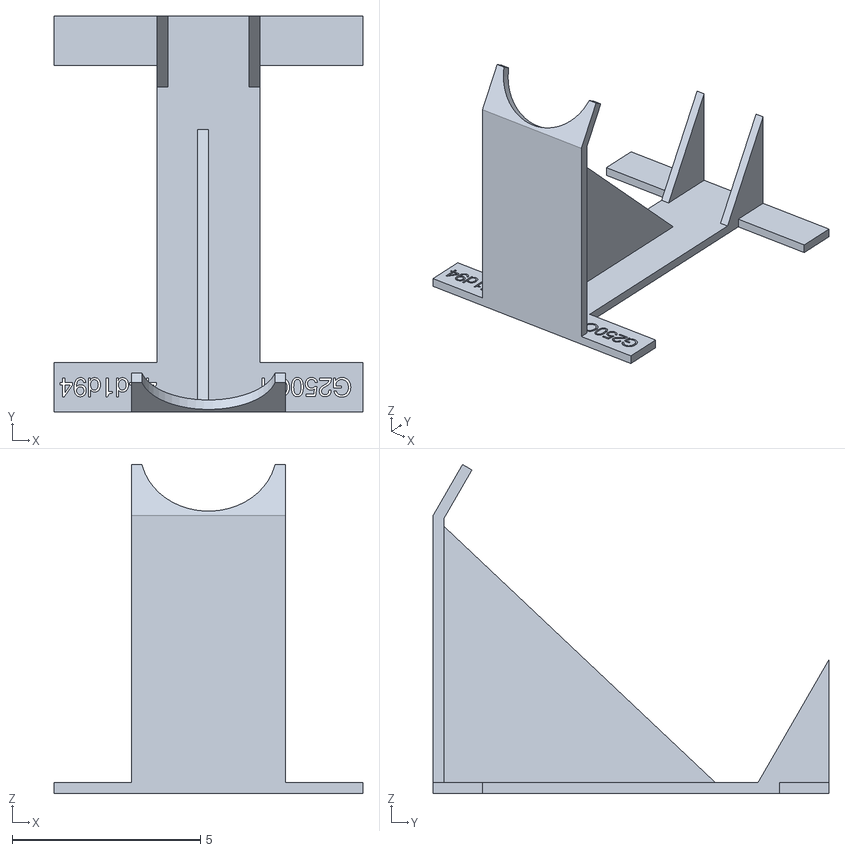
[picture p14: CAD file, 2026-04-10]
models/250ml/holder.stl
8.20 x 10.5 x 8.74

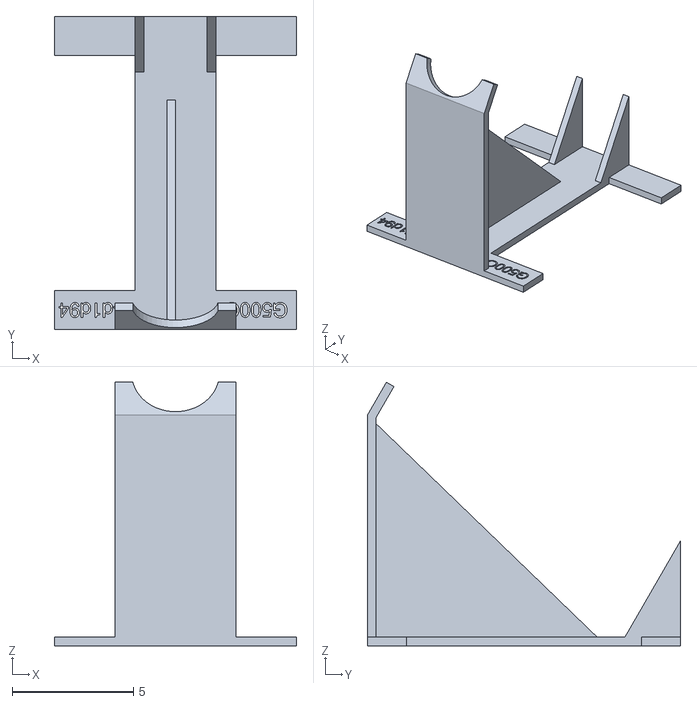
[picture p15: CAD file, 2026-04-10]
models/500ml/holder.stl
10.0 x 12.9 x 10.9

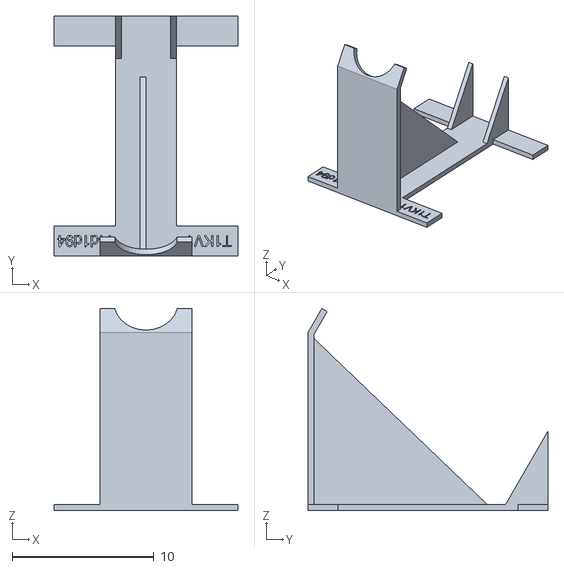
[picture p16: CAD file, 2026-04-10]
models/tarsons_pc_vented_1000ml/holder.stl
13.0 x 16.9 x 14.3

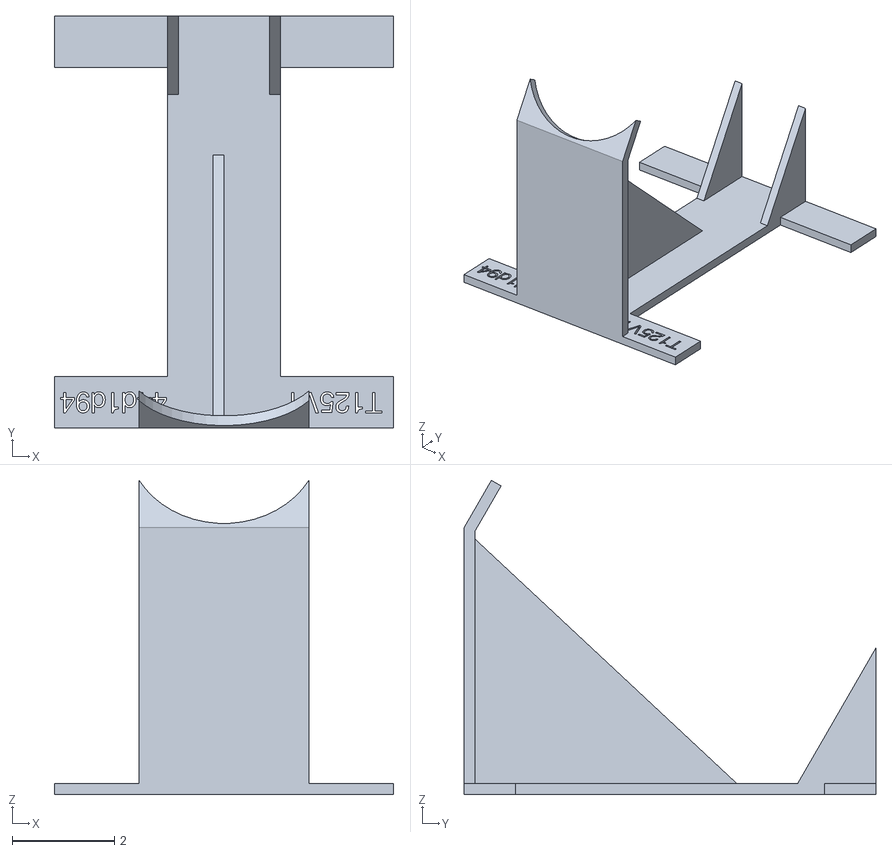
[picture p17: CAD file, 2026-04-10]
models/tarsons_pc_vented_125ml/holder.stl
6.65 x 8.07 x 6.16

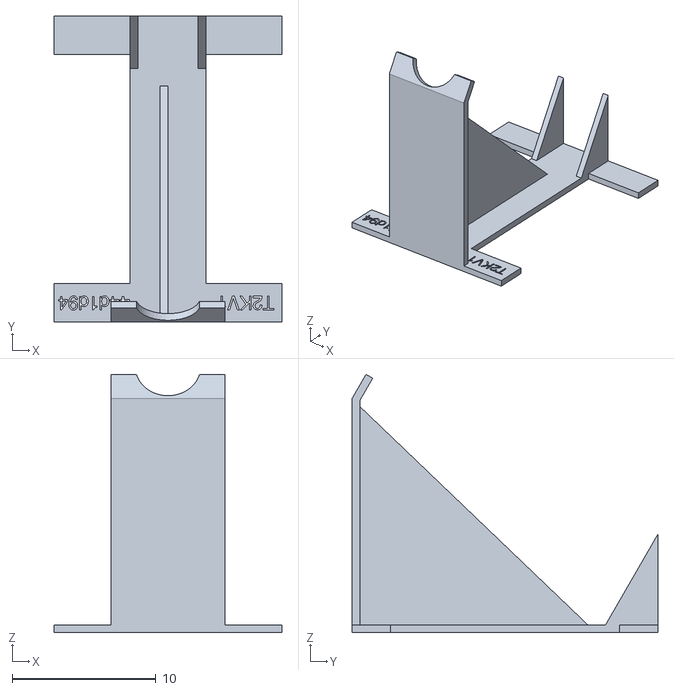
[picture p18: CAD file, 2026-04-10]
models/tarsons_pc_vented_2000ml/holder.stl
15.9 x 21.3 x 18.0

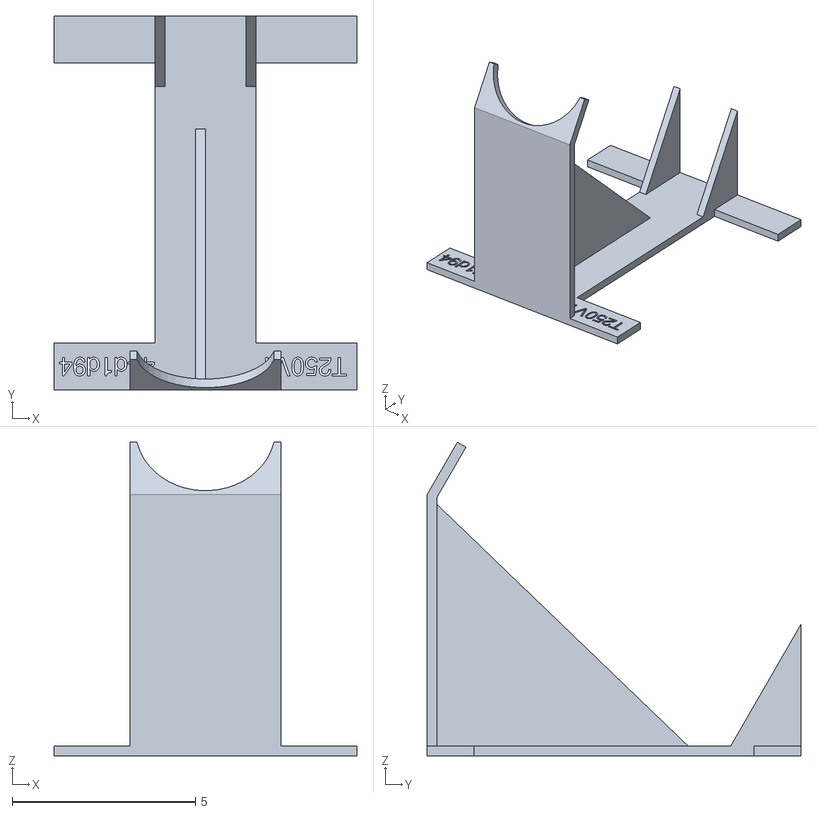
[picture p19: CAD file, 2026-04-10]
models/tarsons_pc_vented_250ml/holder.stl
8.27 x 10.2 x 8.56

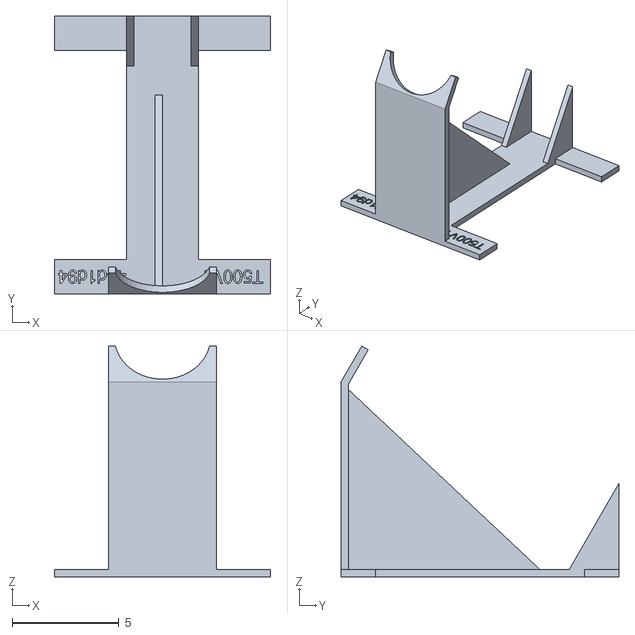
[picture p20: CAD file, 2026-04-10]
models/tarsons_pc_vented_500ml/holder.stl
10.2 x 13.0 x 10.8

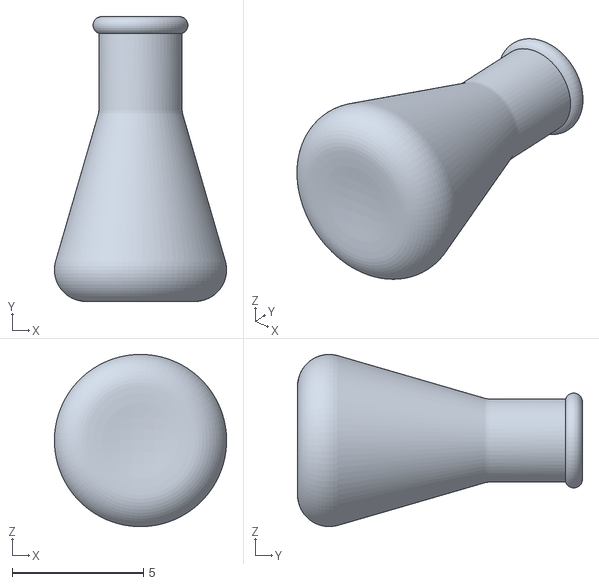
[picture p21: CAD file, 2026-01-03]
models/100ml/erlenmeyer-100ml.stl
6.56 x 10.9 x 6.56

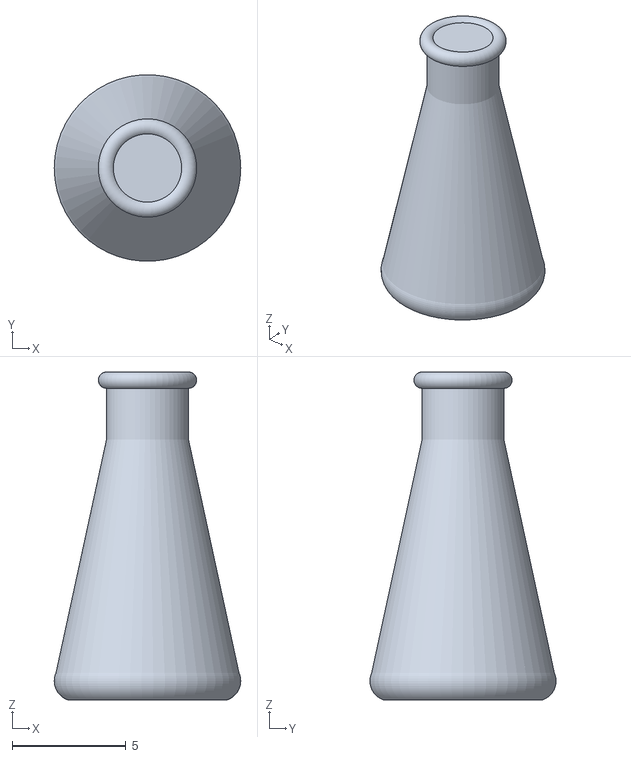
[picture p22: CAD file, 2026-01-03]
models/250ml/flask.stl
8.20 x 8.18 x 14.4

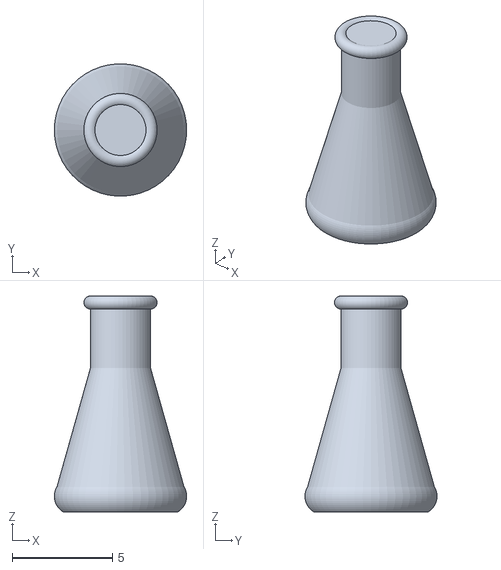
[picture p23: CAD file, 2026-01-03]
models/100ml/flask.stl
6.60 x 6.59 x 10.8

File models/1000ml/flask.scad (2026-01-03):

$fn = 50;

union() {
    translate([0, 0, 2.1666666666667]) {
        hull() {
            translate([0, 0, 2.1666666666667]) {
                cylinder(h=13.166666666667, r2=2.2, r1=4.3333333333333);
            };
            rotate_extrude(convexity=10) {
                translate([4.3333333333333, 0, 0]) {
                    circle(r=2.1666666666667);
                };
            };
        };
    };
    translate([0, 0, 17.5]) {
        union() {
            cylinder(h=4.5, r2=2.2, r1=2.2);
            translate([0, 0, 4.06]) {
                rotate_extrude(convexity=10) {
                    translate([2.2, 0, 0]) {
                        circle(r=0.44);
                    };
                };
            };
        };
    };
};

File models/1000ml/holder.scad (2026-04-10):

$fn = 50;

difference() {
    union() {
        translate([4.3333, 0, 0]) {
            cube([4.3333, 16.6423, 0.44]);
        };
        union() {
            translate([0, 14.562, 0]) {
                cube([13, 2.0803, 0.44]);
            };
            translate([4.3333, 16.6423, 0]) {
                rotate([180, 270, 0]) {
                    linear_extrude(height=0.44) {
                        polygon([[0, 0], [5.6291651245989, 0], [0, 3.25]]);
                    };
                };
            };
            translate([8.2266, 16.6423, 0]) {
                rotate([180, 270, 0]) {
                    linear_extrude(height=0.44) {
                        polygon([[0, 0], [5.6291651245989, 0], [0, 3.25]]);
                    };
                };
            };
        };
        difference() {
            union() {
                cube([13, 2.0803, 0.44]);
                translate([3.25, 0, 0]) {
                    cube([6.5, 0.44, 12.4714]);
                };
                translate([3.25, 0, 12.4714]) {
                    rotate([-30, 0, 0]) {
                        cube([6.5, 0.44, 1.9053]);
                    };
                };
            };
            hull() {
                translate([6.5, 3.4339427193062, 13.2567]) {
                    rotate([60, 0, 0]) {
                        cylinder(h=9, r2=2.205, r1=2.205);
                    };
                };
                translate([6.5, 3.4339427193062, 15.4567]) {
                    rotate([60, 0, 0]) {
                        cylinder(h=9, r2=2.646, r1=2.646);
                    };
                };
            };
        };
        translate([6.5, 0.44, 0.44]) {
            rotate([0, 270, 0]) {
                linear_extrude(height=0.44) {
                    polygon([[0, 0], [11.5864, 0], [0, 11.883433780788]]);
                };
            };
        };
    };
    translate([4.3333, 1.0401, -0.1]) {
        rotate([0, 0, 180]) {
            linear_extrude(height=0.64) {
                text(valign="center", text="44d1d94", halign="left", size=0.78);
            };
        };
    };
    translate([12.56, 1.0401, -0.1]) {
        rotate([0, 0, 180]) {
            linear_extrude(height=0.64) {
                text(valign="center", text="G1KO1", halign="left", size=0.78);
            };
        };
    };
};

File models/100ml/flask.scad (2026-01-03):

$fn = 50;

union() {
    translate([0, 0, 1.1]) {
        hull() {
            translate([0, 0, 1.1]) {
                cylinder(h=5.1, r2=1.5, r1=2.2);
            };
            rotate_extrude(convexity=10) {
                translate([2.2, 0, 0]) {
                    circle(r=1.1);
                };
            };
        };
    };
    translate([0, 0, 7.3]) {
        union() {
            cylinder(h=3.5, r2=1.5, r1=1.5);
            translate([0, 0, 3.2]) {
                rotate_extrude(convexity=10) {
                    translate([1.5, 0, 0]) {
                        circle(r=0.3);
                    };
                };
            };
        };
    };
};

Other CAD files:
models/1000ml/holder_with_flask.scad
models/100ml/holder.scad
models/100ml/holder_with_flask.scad
models/250ml/flask.scad
models/250ml/holder.scad
models/250ml/holder_with_flask.scad
models/500ml/flask.scad
models/500ml/holder.scad
models/500ml/holder_with_flask.scad
models/tarsons_pc_vented_1000ml/flask.scad
models/tarsons_pc_vented_1000ml/holder.scad
models/tarsons_pc_vented_1000ml/holder_with_flask.scad
models/tarsons_pc_vented_125ml/flask.scad
models/tarsons_pc_vented_125ml/holder.scad
models/tarsons_pc_vented_125ml/holder_with_flask.scad
models/tarsons_pc_vented_2000ml/flask.scad
models/tarsons_pc_vented_2000ml/holder.scad
models/tarsons_pc_vented_2000ml/holder_with_flask.scad
models/tarsons_pc_vented_250ml/flask.scad
models/tarsons_pc_vented_250ml/holder.scad
models/tarsons_pc_vented_250ml/holder_with_flask.scad
models/tarsons_pc_vented_500ml/flask.scad
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

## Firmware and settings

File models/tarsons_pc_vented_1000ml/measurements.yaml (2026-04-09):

# measurements in cm
# source_url: https://www.tarsons.com/product/sterile-erlenmeyer-cell-culture-flask-flat-base-pc-with-vented-hdpe-closure/
# note: total_height and base_diameter are published by Tarsons; neck_diameter and neck_height are modeling assumptions documented below.

flask_id: tarsons-cellculture-1000-vented-v1
engraving_id: T1KV1
manufacturer: Tarsons
family_code: cellculture
variant_code: vented
capacity_ml: 1000
revision: 1
product_line: Sterile Erlenmeyer Cell Culture Flask Flat Base PC with vented HDPE Closure
catalog_no: 444240
material: polycarbonate
closure_material: HDPE
closure_style: vented_screw_cap
neck_style: threaded
base_type: flat
rimmed_or_capped: capped
sterile: true
autoclavable: true
baffles: false
source_height_without_closure_mm: 218.0
source_height_with_closure_mm: 222.2
source_bottom_outer_diameter_mm: 129.7
source_inner_neck_diameter_mm: 35.1
source_closure_size: 45-430
neck_height_estimate_mm: 40.0
neck_diameter_model_basis: 45-430 thread finish used as neck OD proxy

total_height: 21.8
neck_height: 4.0
base_diameter: 12.97
neck_diameter: 4.5

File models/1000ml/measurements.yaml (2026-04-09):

# measurements in cm

flask_id: generic-erlenmeyer-1000-open-v1
engraving_id: G1KO1
manufacturer: Generic
family_code: erlenmeyer
variant_code: open
capacity_ml: 1000
revision: 1

total_height: 22.0
neck_height: 4.5
base_diameter: 13.0
neck_diameter: 4.4

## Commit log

2026-01-03 Initial commit: Reorganized parametric CVS holder model with scientific documentation
    [compare_all.scad, compare_flasks.scad, erlenmeyer-100ml.scad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]
2026-01-03 Refactor: Organized flask models into 'models/' directory and cleaned up legacy files
    [compare_all.scad, compare_flasks.scad, erlenmeyer-100ml.scad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]
2026-01-03 refactor: standardize directory names
    - Rename dimentions -> dimensions
    - Rename publication -> publications
    - Rename docs -> documentation
    - Rename src -> source
    - Rename deps -> dependencies
    - Update code and configuration references
    [erlenmeyer-dimensions.csv, holder.stl]
2026-01-03 docs: remove documentation directory and references
    [holder.stl]
2026-01-03 feat: remove 2000ml model support
    [compare_all.scad, flask.scad, front_part.stl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]
2026-01-03 chore: add 100ml reference STL and fix whitespace
    [compare_all.scad, erlenmeyer-100ml.stl]
2026-01-03 docs: adjust pdf margins to 2cm
2026-03-26 Add Tarsons flask models and comparison scenes
    [compare_all.scad, compare_classic_open.scad, compare_tarsons_pc_vented.scad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]
2026-04-07 Keep ruler plate angle while lowering height
2026-04-09 Refine holder fit and add commit ID marking
    [holder.scad, holder.stl, holder_with_flask.scad]
2026-04-09 Update holder geometry and build pipeline
    [holder.scad, holder.stl, holder_with_flask.scad]
2026-04-09 Add flask engraving IDs and project documentation
    [holder.scad, holder_with_flask.scad]
2026-04-10 Add rebuilt artifacts and BGCODE distribution script
    [holder.scad, holder.stl, holder_with_flask.scad]
